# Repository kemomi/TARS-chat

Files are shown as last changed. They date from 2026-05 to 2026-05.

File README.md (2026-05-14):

# TARS-chat



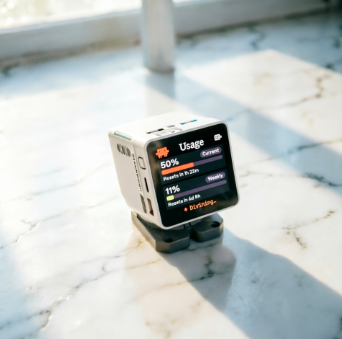
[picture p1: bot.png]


> 一款由 **Python** 驱动、嵌入 **树莓派 4B** 的超可爱迷你桌面机器人。
> 可显示表情、转动头部、对话交流,通过手机/浏览器远程控制。

[👉一起控制它👈](https://kemomi.github.io/TARS-chat/)

[日本語](./README_ja.md) | [English](./README_en.md) | [中文](./README_cn.md)

TARSchat

---

## ✨ 功能特性

- 😄 **丰富表情**: 中性 / 开心 / 难过 / 生气 / 惊讶 / 困倦,支持自定义 PNG 帧序列
- 🎮 **远程摇杆**: 网页拖动实时控制 Pan/Tilt 二自由度云台 (WebSocket 低延迟)
- 🗣️ **语音对话**: 内置 TTS (离线 pyttsx3 / 在线 edge-tts),可扩展 STT
- 🧠 **LLM 大脑**: 支持 OpenAI / Anthropic / 本地 Ollama,对话时自动联动表情与动作
- 🌐 **跨平台控制**: 任意浏览器/手机访问,无需安装 App
- 🔧 **模块化设计**: 舵机、显示、Web、语音、LLM 解耦,容易二次开发
- 📦 **一键部署**: `bash scripts/install.sh` 全自动安装

## 🗂 仓库结构

```
TARS-chat/
├── firmware/          # 树莓派固件 (Python)
│   ├── main.py        # 入口
│   ├── src/           # 核心模块
│   ├── config.yaml    # 配置文件
│   ├── assets/faces/  # 表情资源 (PNG 序列)
│   └── requirements.txt
├── web/               # Web 控制台 (HTML + Socket.IO)
├── schematics/        # 电路接线与原理图
├── stls/              # 3D 打印 STL 文件清单
├── case/              # 外壳设计源文件
├── scripts/           # 安装/测试脚本
├── systemd/           # 开机自启服务
└── docs/              # 文档、图片
```

## 🚀 快速开始

### 硬件准备
1. 看 [`硬件BOM + 接线表 + ASCII 接线图`](./schematics/BOM+接线表+ASCII接线图.md) 准备元件清单并完成接线
2. 看 [`结构件清单`](./stls/README.md) 打印 3D 结构件和所需的元器件 [`BOM清单`](./stls/BOM.md)
3. 装配机器人

### 烧录固件
```bash
git clone https://github.com/kemomi/TARS-chat.git
cd TARS-chat
pip install requirements.txt #安装依赖和环境
bash scripts/install.sh  #启动脚本
```

详细步骤见 [`固件烧录`](./firmware/固件安装文档.md)。

### 开始使用
```bash
sudo systemctl enable --now tars-chat
```
浏览器打开 `http://<树莓派IP>:8080` 即可看到控制台。

## 🛠 开发工作流

```bash
cd firmware
source venv/bin/activate
python ../scripts/test_servo.py   # 舵机自检
python main.py                    # 前台调试
```

修改 `../firmware/src/` 下任意文件后自启:
```bash
sudo systemctl restart tars-chat
```

## 📡 通信协议

| 类型 | 路径 | 说明 |
|---|---|---|
| HTTP POST | `/api/face` | `{expression:"happy"}` |
| HTTP POST | `/api/servo` | `{action:"set",pan:90,tilt:80}` 或 `nod`/`shake`/`center` |
| HTTP POST | `/api/speak` | `{text:"你好"}` |
| HTTP POST | `/api/chat` | `{text:"今天天气如何"}` — LLM 对话 |
| HTTP POST | `/api/chat/reset` | 清空对话历史 |
| HTTP GET  | `/api/status` | 查询当前状态 |
| WebSocket | `servo_stream` | 实时摇杆推流 (低延迟) |
| WebSocket | `dialogue_event`  | 多端对话同步 |

详细字段见 [`docs/API.md`](./docs/API.md)。LLM 接入见 [`docs/LLM.md`](./docs/LLM.md)。

## 🗺 路线图

见 [`ROADMAP`](./ROADMAP.md)。

## 🆙 Update docs

见[`更新文档`](./docs/更新文档.md)

## 🤝 贡献

欢迎提 Issue 与 PR!参与方式见 [`CONTRIBUTING`](./CONTRIBUTING.md)。

## 📄 许可证

[Apache 2.0](./LICENSE)

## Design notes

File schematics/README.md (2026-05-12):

# 硬件接线说明

## BOM (Bill of Materials)

| 序号 | 名称 | 数量 | 备注 |
|---|---|---|---|
| 1 | 树莓派 4B (2GB+)  | 1 | 主控,也可用 Pi Zero 2W |
| 2 | MicroSD 卡 32GB | 1 | Class 10 以上 |
| 3 | SG90 / MG90S 舵机 | 2 | Pan + Tilt 二自由度 |
| 4 | 3.5" HDMI / SPI 屏 | 1 | 320×240 或 480×320 |
| 5 | UBEC 5V 3A | 1 | 给舵机单独供电(关键!) |
| 6 | 18650 电池座 ×2 | 1 | 7.4V 输入 |
| 7 | 杜邦线若干 | - | 母对母 |
| 8 | M2/M3 螺丝包 | 1 | 与 STL 文件配套 |
| 9 | (可选) USB 麦克风  | 1 | 启用语音对话时需要 |
| 10 | (可选) 小喇叭 8Ω  | 1 | TTS 输出 |

> ⚠️ **关键提示**: 千万不要让舵机直接从树莓派 5V 引脚取电!舵机启动电流大,会导致树莓派复位。必须用独立 UBEC/降压模块。
关键避坑:舵机一定要走独立 UBEC 供电,千万别从树莓派 5V 引脚拉,会反复重启。 ASCII 接线图照着接就行

## GPIO 接线表

树莓派引脚使用 **BCM 编号**(`config.yaml` 中的 `pan_pin` 与 `tilt_pin` 也是 BCM)。

| 信号 | BCM | 物理引脚 | 接到 |
|---|-----|---|---|
| Pan 信号线 | 18  | 12 | 水平舵机橙色线 |
| Tilt 信号线| 13  | 33 | 俯仰舵机橙色线 |
| 公共 GND | - | 6 / 9 | UBEC GND + 舵机棕色线 |
| 5V (屏幕)  | - | 2 / 4 | HDMI 屏供电(若用 USB 供电就不接) |

**舵机供电独立走 UBEC**:
- UBEC 输入: 7.4V (电池) 或 12V 适配器
- UBEC 输出: 5V → 舵机红色线
- UBEC GND 必须与树莓派 GND **共地**

## 接线图(ASCII)

```
                 ┌──────────────────────┐
   电池 7.4V ───►│ UBEC 5V/3A           │──► 5V ───┬──► Pan 舵机 红
                 │                      │          └──► Tilt 舵机 红
                 │                      │──► GND ──┬──► Pan 舵机 棕
                 └──────────────────────┘          ├──► Tilt 舵机 棕
                                                   │
                       ┌─────────────────┐         │
   HDMI 屏 ◄───────────│ 树莓派 4B       │         │
                       │                 │         │
                       │   BCM 18 (Pin12)│──────────────► Pan 舵机 橙
                       │   BCM 13 (Pin33)│──────────────► Tilt 舵机 橙
                       │   GND (Pin 6)   │─────────┘
                       │                 │
                       │   USB ──────────│──► USB 麦克风 (可选)
                       │   3.5mm ────────│──► 小喇叭 (可选)
                       └─────────────────┘
```

## PCB(可选)

如果你想做转接板,本目录下应放置:
- `schematic.kicad_sch` — KiCad 原理图
- `pcb.kicad_pcb` — PCB 布线
- `gerber/` — 送厂打样用的 Gerber 文件

> 这些文件需要你用 KiCad 自行绘制,本仓库提供接线参考即可在面包板上跑通。

## 自检步骤

1. **不接舵机**先开机,确认树莓派、屏幕、网络正常
2. 连接舵机信号线,不接电源
3. 接通 UBEC,观察舵机是否轻微回中
4. 启动固件: `python main.py`
5. 浏览器打开 `http://<树莓派 IP>:8080` 测试摇杆

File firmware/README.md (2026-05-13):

# 固件安装指南

## 1. 系统要求

- 树莓派 4B / 3B+ / Zero 2W
- Raspberry Pi OS (Bookworm 或更新版本,64-bit 推荐)
- Python 3.9+

## 2. 一键安装

```bash
git clone https://github.com/kemomi/TARS-chat.git
cd TARS-chat
bash scripts/install.sh
```

`install.sh` 会自动完成:
- 安装 APT 依赖(pigpio、SDL2 等)
- 创建 Python 虚拟环境
- 安装 `requirements.txt`
- 启动 `pigpiod` 守护进程
- 注册 systemd 服务

## 3. 手动安装(如果自动脚本失败)

### 3.1 系统依赖

```bash
sudo apt update
sudo apt install -y python3-pip python3-venv python3-dev \
    pigpio python3-pigpio \
    libsdl2-dev libsdl2-image-dev libsdl2-ttf-dev \
    libportaudio2 \
    mpg123 espeak-ng
sudo systemctl enable --now pigpiod
```

### 3.2 Python 依赖

```bash
cd firmware
python3 -m venv venv
source venv/bin/activate
pip install --upgrade pip
pip install -r requirements.txt
```

### 3.3 运行(前台调试)

```bash
cd firmware
source venv/bin/activate
python main.py
```

此时浏览器访问 `http://<树莓派IP>:8080` 应该能看到控制台。

## 4. 开机自启 (systemd)

```bash
sudo cp systemd/tars-chat.service /etc/systemd/system/
sudo systemctl daemon-reload
sudo systemctl enable --now tars-chat
sudo systemctl status tars-chat   # 查看状态
```

查看日志:
```bash
journalctl -u tars-chat -f
# 或
tail -f /var/log/tars-chat.log
```

## 5. 配置说明

所有可调参数都在 `firmware/config.yaml`,常见修改:

| 项 | 说明 |
|---|---|
| `servo.pan_pin` | 如果接线换了 GPIO,改这里 |
| `servo.pan_range` | 缩小范围防止打到外壳 |
| `display.width/height` | 匹配你的屏幕分辨率 |
| `voice.enabled` | `true` 启用语音(需先装 pyttsx3 或 edge-tts) |
| `web.port` | 改 80 端口需要 `sudo` |

修改后重启服务:
```bash
sudo systemctl restart tars-chat
```

## 6. 常见问题

### Q1: 舵机疯狂抖动 / 不动?
- 检查是否启动 pigpiod: `sudo systemctl status pigpiod`
- 舵机必须有**独立 5V 供电**,不能从 Pi 引脚取电
- GND 必须共地

### Q2: `http://<IP>:8080` 打不开?
- 检查防火墙: `sudo ufw allow 8080`
- 确认服务运行: `sudo systemctl status tars-chat`
- 同一局域网内访问

### Q3: 表情不显示,只有占位文字?
- 检查 `firmware/assets/faces/` 下是否有 PNG 文件
- 资源规格见 [assets/faces/README.md](../assets/faces/README.md)

### Q4: 想脱离桌面环境跑(纯命令行启动)?
- 编辑 `src/face_display.py` 中的 `SDL_VIDEODRIVER`,改为 `"kmsdrm"`
- 或在 systemd 服务文件里加 `Environment=SDL_VIDEODRIVER=kmsdrm`

### Q5: 我用的不是树莓派,是 ESP32 / M5Stack?
- 本固件目前仅适配树莓派
- 如要移植到 MCU,需要重写舵机/显示驱动,但 Web 端协议(HTTP + Socket.IO)可以保留作为通信层

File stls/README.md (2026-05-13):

<!--
 * @Author: fbee3157 fbee3157@outlook.com
 * @Date: 2026-05-13 17:30:39
 * @LastEditors: fbee3157 fbee3157@outlook.com
 * @LastEditTime: 2026-05-13 17:31:47
 * @FilePath: \TARS-chat\stls\README.md
 * @Description: 这是默认设置,请设置`customMade`, 打开koroFileHeader查看配置 进行设置: https://github.com/OBKoro1/koro1FileHeader/wiki/%E9%85%8D%E7%BD%AE
-->
# 3D 打印件清单

本目录应包含以下 STL 文件(由你根据自己的尺寸建模或从社区下载)。下表为推荐结构,可作为建模依据。

## 文件清单

| 文件名 | 数量 | 推荐参数 | 说明 |
|---|---|---|---|
| `base.stl` | 1 | 0.2mm 层高 / 25% 填充 / 支撑 | 底座,容纳电池和电路板 |
| `body_front.stl` | 1 | 0.2mm / 20% / 无需支撑 | 机身前壳,挖屏幕窗口 |
| `body_back.stl` | 1 | 0.2mm / 20% / 无需支撑 | 机身后壳,留散热孔与接口 |
| `neck_tilt_arm.stl` | 1 | 0.16mm / 40% / 树状支撑 | 俯仰摆臂(连接 Tilt 舵机) |
| `neck_pan_base.stl` | 1 | 0.16mm / 40% | 水平转盘 |
| `servo_horn_adapter.stl`| 2 | 0.12mm / 80% | 舵机臂转接,匹配 SG90 出厂角  |
| `head_shell.stl` | 1 | 0.2mm / 15% | 头部外壳(屏幕载体) |
| `head_cover_top.stl` | 1 | 0.2mm / 15% | 顶盖 |
| `cable_clip.stl` | 2 | 0.2mm / 30% | 走线卡扣 |

## 推荐打印参数

- **材料**: PLA(室内桌面用足够;若放车里建议 PETG/ABS)
- **喷嘴**: 0.4mm
- **层高**: 外壳 0.2mm,关节 0.16mm
- **打印速度**: 50mm/s
- **温度**: 喷嘴 210°C / 热床 60°C(PLA)

## 螺丝清单(配套)

| 规格 | 数量 | 用途 |
|---|---|---|
| M2 × 6mm 自攻 | 8 | 舵机臂固定 |
| M3 × 8mm 自攻 | 12 | 机身合壳 |
| M3 × 16mm 内六角 | 4 | 底座承重 |

## 装配顺序

1. 打印全部 STL,用美工刀去除支撑毛刺
2. 把 Pan 舵机塞入 `neck_pan_base.stl` 槽位,用 M2 螺丝固定
3. `servo_horn_adapter.stl` 卡到 Pan 舵机臂上,再装到 `neck_tilt_arm.stl`
4. Tilt 舵机同理装入摆臂
5. 屏幕用双面胶或卡扣固定到 `head_shell.stl` 的窗口内
6. 树莓派、UBEC、电池座放入 `base.stl`,走线从顶部孔上来
7. 合壳前先通电测试一遍舵机方向,有问题就 `config.yaml` 里翻转角度范围

## 没有建模文件怎么办?

如果你还没有现成 STL,可以:
- **方案 A**: 用 Fusion 360 / OnShape 按上表自己建模(舵机槽尺寸 22.5×11.8×22.7mm)
- **方案 B**: 上 [Thingiverse](https://www.thingiverse.com/) / [Printables](https://www.printables.com/) 搜索 "Pan tilt camera mount SG90",选一套尺寸近的改一下
- **方案 C**: 直接买现成的舵机云台 + 亚克力外壳,跳过 3D 打印

> 建模完成后,把 STL 文件按上面的命名规则丢到本目录即可。

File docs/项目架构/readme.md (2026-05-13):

# TARS-chat 项目架构

## 一、目录结构

```
TARS-chat/
├── firmware/                      # 🎯 核心固件 (运行在树莓派)
│   ├── main.py                    # 启动入口,按序初始化各模块
│   ├── config.yaml                # 全局配置 (所有功能开关都在这)
│   ├── requirements.txt           # Python 依赖
│   ├── README.md                  # 固件安装指南
│   ├── assets/faces/              # 表情 PNG 帧序列
│   │   └── README.md
│   └── src/                       # 模块化代码
│       ├── __init__.py
│       ├── servo_controller.py    # 🦾 舵机控制 (Pan/Tilt 云台)
│       ├── face_display.py        # 😊 表情显示 (Pygame 渲染)
│       ├── voice_module.py        # 🗣️ TTS 语音播报
│       ├── camera_module.py       # 📷 摄像头采集
│       ├── face_tracker.py        # 👁️ 人脸检测 + 跟踪
│       ├── llm_provider.py        # 🧠 LLM 抽象层 (OpenAI/Anthropic/Ollama)
│       ├── dialogue.py            # 🎭 对话编排器 (整合 LLM/动作/语音/视觉)
│       └── web_server.py          # 🌐 Flask + Socket.IO 服务
│
├── web/                           # 🌐 Web 控制台 (前端)
│   └── web_control.html           # 单页应用 (表情/摇杆/对话/摄像头)
│
├── docs/                          # 📚 文档
│   ├── API.md                     # HTTP/WebSocket 接口
│   ├── LLM.md                     # 三种 LLM 后端接入指南
│   ├── CAMERA.md                  # 摄像头与视觉问答指南
│   └── ROADMAP.md                 # 版本规划
│
├── schematics/                    # ⚡ 电路设计
│   └── README.md                  # BOM + 接线表 + ASCII 接线图
│
├── stls/                          # 🖨️ 3D 打印件
│   └── README.md                  # 结构件清单 + 打印参数
│
├── case/                          # 📦 外壳源文件
│   └── README.md
│
├── scripts/                       # 🔧 工具脚本
│   ├── install.sh                 # 一键安装 (apt + pip + systemd)
│   └── test_servo.py              # 舵机自检
│
├── systemd/                       # 🚀 开机自启
│   └── tars-chat.service          # systemd unit
│
├── .github/workflows/
│   └── build.yml                  # CI: 语法检查 + 导入冒烟测试
│
├── README.md                      # 项目主页
├── CONTRIBUTING.md
├── LICENSE                        # Apache 2.0
└── .gitignore
```

## 二、分层架构

整个系统分四层,自顶向下:



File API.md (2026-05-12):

# API 参考

固件提供两套通信接口:**HTTP REST** 用于命令式控制,**WebSocket (Socket.IO)** 用于实时数据流。

Base URL: `http://<树莓派IP>:8080`

---

## HTTP REST API

### `GET /api/status`
查询当前所有状态。

**响应**
```json
{
  "ok": true,
  "servo": {"pan": 90, "tilt": 90, "backend": "pigpio"},
  "face": {
    "current": "neutral",
    "available": ["neutral", "happy", "sad", "angry", "surprised", "sleepy"]
  },
  "voice_enabled": false
}
```

### `POST /api/face`
切换表情。

**请求**
```json
{ "expression": "happy" }
```

**响应**
```json
{ "ok": true, "expression": "happy" }
```

### `POST /api/servo`
舵机控制。

**请求(set)**
```json
{ "action": "set", "pan": 120, "tilt": 80 }
```

**请求(其他动作)**
```json
{ "action": "center" }      // 回中
{ "action": "nod", "times": 2 }    // 点头
{ "action": "shake", "times": 3 }  // 摇头
```

**响应**
```json
{ "ok": true, "status": {"pan": 120, "tilt": 80, "backend": "pigpio"} }
```

### `POST /api/speak`
TTS 播报(需启用 voice)。

**请求**
```json
{ "text": "你好,我是 TARS。" }
```

### `POST /api/chat`
LLM 对话(需启用 llm,详见 [`LLM.md`](./LLM.md))。机器人会自动联动表情、动作和 TTS。

**请求**
```json
{ "text": "今天北京天气怎么样" }
```

**响应**
```json
{
  "ok": true,
  "response": {
    "say": "我没法查天气,你打开窗看看吧",
    "expression": "neutral",
    "motion": "shake"
  }
}
```

### `POST /api/chat/reset`
清空对话上下文,机器人会"忘记"之前的内容。
```json
{ "ok": true }
```

---

## WebSocket (Socket.IO)

### 客户端 → 服务端

#### `servo_stream`
摇杆实时推流,建议节流到 20~50ms 一次。

```js
socket.emit("servo_stream", { pan: 110, tilt: 95 });
```

### 服务端 → 客户端

#### `hello`
连接建立时推送。
```json
{ "msg": "TARS-chat ready" }
```

#### `face_changed`
任意端切换表情后广播,用于多端同步。
```json
{ "expression": "sad" }
```

#### `dialogue_event`
任意端发起 LLM 对话后广播。
```json
{
  "user": "你好",
  "response": {"say":"嗨!","expression":"happy","motion":"nod"}
}
```

---

## 第三方调用示例

### curl
```bash
curl -X POST http://192.168.1.10:8080/api/face \
     -H "Content-Type: application/json" \
     -d '{"expression":"happy"}'
```

### Python
```python
import requests
requests.post("http://192.168.1.10:8080/api/servo",
              json={"action": "set", "pan": 60, "tilt": 90})
```

### Home Assistant (REST command)
```yaml
rest_command:
  tars_happy:
    url: "http://192.168.1.10:8080/api/face"
    method: POST
    headers: { Content-Type: "application/json" }
    payload: '{"expression":"happy"}'
```

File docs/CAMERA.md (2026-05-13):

# 摄像头与人脸跟踪

TARS-chat 支持两类摄像头,自动探测:

| 摄像头 | 后端 | 备注 |
|---|---|---|
| Pi Camera v1/v2/v3, HQ Camera | picamera2 | 走 CSI 排线, 推荐 |
| USB UVC 摄像头 | opencv (V4L2) | 即插即用, 800 多万像素以下都行 |

---

## 1. 硬件准备

### CSI 摄像头(推荐)
- 树莓派 4B 有两个相机接口,接 CAM 那个
- 排线注意金属触点方向:Pi 侧朝 HDMI、摄像头侧朝镜头
- `raspi-config` → Interface Options → Camera 启用 (Bookworm 默认已启)

### USB 摄像头
- 直接插 USB,`ls /dev/video*` 看是否有 `/dev/video0`
- 多个摄像头时改 `config.yaml` 里 `device_index: 1` 之类

### 散热
人脸检测吃 CPU,Pi 4 全速跑约 50% 占用。如果没散热片建议加一个,不然降频之后会卡顿。

---

## 2. 安装依赖

### CSI 摄像头
```bash
sudo apt install -y python3-picamera2 python3-libcamera
```

### USB 摄像头
opencv 在树莓派上**强烈推荐 apt 装**,从 pip 装会编译几个小时:
```bash
sudo apt install -y python3-opencv libatlas-base-dev libjasper-dev
```

然后修改 `firmware/requirements.txt`,把 `opencv-python-headless` 那一行注释掉(避免 pip 重新装一遍冲突)。

测试摄像头能否被读到:
```bash
# CSI:
libcamera-hello -t 2000
# USB:
v4l2-ctl --list-devices
ffplay /dev/video0
```

---

## 3. 启用配置

`firmware/config.yaml`:

```yaml
camera:
  enabled: true            # ← 改这里
  width: 640
  height: 480
  fps: 15
  device_index: 0          # USB 用,CSI 摄像头忽略
  tracking:
    enabled: true          # 加载跟踪模块
    autostart: false       # true = 开机就跟踪 / false = Web 端手动开启
    pan_gain: 0.05         # 左右跟踪强度
    tilt_gain: 0.04        # 上下跟踪强度
    deadzone_pct: 0.08     # 中心 ±8% 不动 (防抖)
    lost_timeout: 1.5      # 失去目标 N 秒后回中
    detect_fps: 10         # 检测帧率
    min_face_size: 60      # 小于此像素的脸不识别
```

重启服务:
```bash
sudo systemctl restart tars-chat
```

---

## 4. 使用

启用后,Web 控制台会多出一个"视觉"卡片:

- **预览**:实时 MJPEG 推流,~15 FPS
- **绿色方框**:检测到人脸 + 跟踪开启
- **橙色方框**:检测到人脸,但跟踪未开
- **状态文字**:`SEARCHING` / `LOCKED` / `TRACKING`
- **人脸跟踪开关**:打开后舵机会自动跟着脸转
- **📷 拍照问**:拍一张照片连同问题一起发给 LLM (需要 vision 模型,如 gpt-4o)

---

## 5. 跟踪算法原理

```
摄像头帧 ──► Haar 级联检测 ──► 取最大人脸框 ──► 计算偏移
                                                  │
                                                  ▼
                          err_x = (face_cx - frame_cx) / (frame_cx)
                                                  │
                                       │err_x│ > deadzone?
                                              │ 否 ──► 不动
                                              │ 是
                                              ▼
                          pan_target = current_pan - err_x × gain × 90°
                                                  │
                                                  ▼
                                            servo.set_pan()
```

**为什么是 P-only 而不是 PID?** 摄像头检测有延迟(~70ms),又有积分项会震荡。比例控制 + 死区已经够稳。

**舵机转反了怎么办?** 把 `pan_gain` 或 `tilt_gain` 改成负数即可。

---

## 6. 视觉问答 (LLM with Vision)

`dialogue.py` 中的 `DialogueOrchestrator.chat()` 会自动检测以下关键词:
- 中文:`看到 / 看看 / 看一下 / 你看 / 前面 / 周围 / 环境 / 现在拍`
- 英文:`what do you see / look at / describe`

匹配时自动拍一张照片附加给 LLM。

**前提**: LLM Provider 需要支持视觉:
- ✅ OpenAI: `gpt-4o`, `gpt-4o-mini`, `gpt-4-vision-preview`
- ✅ Anthropic: `claude-haiku-4-5-20251001`, `claude-sonnet-4-6` (任意 Claude 3+ 都行)
- ❌ Ollama: 默认 `qwen2.5` 不支持,需换 `llava` / `qwen2-vl` 等多模态模型

示例对话:
```
你: "你前面有什么东西?"
TARS: "我看到一台笔记本电脑,屏幕上有一些代码,旁边有一杯咖啡。"  (顺便会点头)
```

---

## 7. 故障排查

### Q1: Web 端"视觉"卡片不显示
- 检查 `config.yaml` 中 `camera.enabled: true`
- 日志看是否报错: `journalctl -u tars-chat -n 50 | grep -i camera`

### Q2: 黑屏 / "无法打开摄像头"
- CSI: `libcamera-hello` 测一下,可能是排线松了
- USB: 检查 `/dev/video0` 是否存在;有时插着插着掉线,拔出来重插

### Q3: 人脸检测一闪一闪
- 光线太暗,Haar 算法在弱光下不稳定
- 把 `min_face_size` 调大到 80~100,过滤误检
- 增加 `min_neighbors` (在 face_tracker.py 里改)

### Q4: 舵机跟着人脸狂抖
- `pan_gain / tilt_gain` 太大,改小到 0.03 试试
- `deadzone_pct` 加大到 0.12
- 或者 `detect_fps` 降到 5(检测慢一点,反应不那么激进)

### Q5: 占 CPU 太高
- 降低 `camera.fps` 到 10
- 降低 `tracking.detect_fps` 到 5
- 降低 `camera.width/height` 到 320×240

### Q6: MJPEG 推流卡顿
- Pi 上同时跑 picamera2 + 推流会吃满网络,改用 320×240
- 或者只在需要看时才打开 Web 端 (推流是按需的)

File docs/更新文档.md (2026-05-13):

<!--
 * @Author: fbee3157 fbee3157@outlook.com
 * @Date: 2026-05-12 17:09:08
 * @LastEditors: fbee3157 fbee3157@outlook.com
 * @LastEditTime: 2026-05-13 14:55:13
 * @FilePath: \TARS-chat\docs\更新文档.md
 * @Description: 这是默认设置,请设置`customMade`, 打开koroFileHeader查看配置 进行设置: https://github.com/OBKoro1/koro1FileHeader/wiki/%E9%85%8D%E7%BD%AE
-->
# 部署流程

```bash
unzip TARS-chat.zip && cd TARS-chat
bash scripts/install.sh        # 一键装依赖 + systemd
python scripts/test_servo.py   # 先单独测舵机会不会动
sudo systemctl start tars-chat # 启动
# 浏览器打开 http://<树莓派IP>:8080
```
------------------------------------------------------------

V0.0.3-20260512

完成摄像头 + 人脸跟踪 + 视觉问答完成。
1. 摄像头双后端自动降级:picamera2(CSI) → opencv(USB) → mock。开发时没硬件也能跑,Web 控制台会显示一张"NO CAMERA"的占位图,所有 API 都不会崩。
2. 跟踪用 P-only 而不是 PID:摄像头检测有 70ms 左右延迟,积分项会让头部震荡。比例控制 + 中心 8% 死区,实测够稳。pan_gain / tilt_gain 是负的就反向跟踪——舵机装反时不用拆开,改 yaml 就行。

3. 视觉问答有两种触发方式:
隐式:dialogue 自动检测 "看到/前面/周围" 这类关键词,匹配就自动拍照附给 LLM
显式:Web 端"📷 拍照问"按钮、API 传 vision: true 强制走视觉

4. Anthropic 和 OpenAI 的 vision 消息格式不一样:

OpenAI 用 {type:"image_url", image_url:{url:"data:..."}},
Anthropic 用 {type:"image", source:{type:"base64",...}}。

在 BaseLLMProvider 里留了 _build_vision_message 钩子,Anthropic 子类重写就好。
5. MJPEG 推流帧上直接画检测框:在 Flask generator 里读 tracker.last_box 调 detector.draw() 叠加,前端只要  就能看到带框的实时画面,不用单独的画布 + WebSocket。
6. 截图用单独的内存 buffer:snapshot_base64() 编码质量 85,推流编码质量 70(省带宽)。给 LLM 的图要清楚一点,给浏览器看的图压一点没事。

几个使用注意
Pi 上一定 apt 装 OpenCV,别走 pip,后者要编译 4 小时还可能 OOM。
安装脚本已经处理了:venv --system-site-packages 让虚拟环境能用 apt 装的 cv2 和 picamera2
视觉问答必须用支持 vision 的模型:OpenAI 用 gpt-4o-mini,Anthropic 用任何 Claude 3+,Ollama 用 llava/qwen2-vl。普通文本模型收到图片会直接报错或忽略
跟踪反向了:看下舵机装的方向,把 pan_gain 或 tilt_gain 改成负数;不用改硬件

CPU 紧张:Pi 4 上同时跑 LLM 客户端 + 摄像头 + 表情显示,温度会上去。建议加散热片;或者把 detect_fps 降到 5,camera.fps 降到 10

下一个扩展是之前提过的还有两个:OpenSCAD 参数化外壳(把 STL 文件给你)和 STT 语音输入(让机器人能听见你说话,而不只是打字)。

V0.0.2-20260512

feat:更新几个设计决定:
1. 三种 Provider 用同一个抽象基类:OpenAIProvider、AnthropicProvider、OllamaProvider 都继承 BaseLLMProvider,只用实现 _chat() 一个方法。
换 Provider 只需要改 config.yaml 一行,不用动代码。
2. LLM 返回的是结构化指令,不是纯文本。LLM 输出 JSON {say, expression, motion},然后 DialogueOrchestrator 把三个字段分发给表情、舵机、TTS 三路并发执行——这样机器人会"一边点头一边说话",而不是"先说完再点头",体感差很多。
3. 容错降级:小模型(0.5B 这种)经常不遵守 JSON 格式,做了正则清洗 + JSON 解析失败时降级把整段当作 say,机器人虽然不动作但至少能说话,不会崩。
4. Anthropic API 的特殊处理:它的 system prompt 是单独字段,不在 messages 数组里,这个坑我已经在 AnthropicProvider._chat 里处理了。

几个使用建议:
最快上手:直接填 OpenAI key,5 分钟跑通。把 key 放环境变量别提交到 git
追求隐私:外接一台电脑跑 Ollama (OLLAMA_HOST=0.0.0.0:11434),让 Pi 通过局域网调用,比在 Pi 上本地跑流畅 10 倍
改性格:config.yaml 里改 system_prompt,记得保留 JSON 输出格式说明,否则编排器拿不到表情/动作字段
测试:不接舵机也能验证,mock 模式会把所有动作打日志

详细文档在 docs/LLM.md,三种后端的接入步骤、故障排查都在里面。
下一个准备做摄像头人脸跟踪还是再迭代 LLM(比如加流式输出/STT 让机器人能听)
Tars chatZIP ：
Download Llm providerPY Download DialoguePY DownloadConfigYAML DownloadWeb serverPY DownloadMainPY DownloadWeb controlCode · HTML Download LlmDocument · MD Download Download all

V0.0.1-20260512

1. 原 web_control.html 是纯前端模拟,按钮只会 alert() 提示。
add(fate)：新版本通过 Flask + Socket.IO 真正打通了浏览器 → 树莓派 → 舵机/屏幕/扬声器的链路,摇杆是通过 WebSocket 实时推流的(50ms 节流),延迟感觉跟玩游戏差不多。
2. 原 README "Rust + Python 驱动"
add(md)：新版本提供了完整 Python 固件,4 个核心模块解耦(舵机、表情、语音、Web),每个都可以单独测试。
3. 舵机后端三选一自动降级:优先 pigpio(硬件 PWM 抖动最小)→ 退到 RPi.GPIO(软件 PWM)→ 退到 Mock(在 Mac/Windows 上开发也能跑,只打日志不真的转)。这样即便没接树莓派也能调 Web 端。
4. 3D 打印:stls/README.md 推荐的 9 个结构件清单和打印参数,但仓库里没有实际的 .stl 文件——因为我没法在这里建模。
三个选项:
（1） 用 Fusion 360 / OnShape 按清单尺寸自己建(舵机槽 22.5×11.8×22.7mm 是 SG90 标准)
（2）上 Thingiverse 搜 "Pan tilt SG90 mount" 找现成的改一下
（3）直接买现成的舵机云台跳过 3D 打印这步

-------------------------------------------------------------------

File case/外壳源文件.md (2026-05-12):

# 外壳与组装

外壳的 STL 模型放在仓库 [stls/](../stls/) 目录,本目录用于放置:

- 外壳设计源文件 (`.f3d` / `.step` / `.scad`)
- 渲染效果图
- 装配视频/动图

## 整体尺寸参考

- 高度: ~180mm(含头部)
- 底座: 120 × 120mm
- 头部: 80 × 80 × 70mm

详细的打印参数与装配顺序见 [stls/README.md](../stls/README.md)。

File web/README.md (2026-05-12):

# 表情资源目录

将 PNG 序列帧放到对应子目录:

```
assets/faces/
├── neutral/      # 中性
│   ├── 0001.png
│   └── 0002.png  (可选,多帧自动循环作为眨眼)
├── happy/
├── sad/
├── angry/
├── surprised/
└── sleepy/
```

## 规格要求
- 分辨率: 与 `config.yaml` 中 `display.width × display.height` 一致(默认 320×240)
- 格式: PNG(支持透明背景)
- 文件名: 按 `0001.png`、`0002.png` 顺序命名,固件会自动按字典序循环
- 帧率: 固件默认按 10 FPS 播放

## 找不到资源会怎样?
固件会在屏幕上渲染占位文字(例如 `:: happy ::`),不会崩溃。

## 推荐做法
1. 用 Aseprite / Procreate / Photoshop 画 6 套像素风表情
2. 每套表情 2-4 帧形成"呼吸感"
3. 单帧也可,只是静态显示

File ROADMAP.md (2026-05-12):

# 路线图

## v0.1 (MVP) ✅
- [x] Pan/Tilt 舵机基础控制
- [x] 6 种表情显示
- [x] Web 控制台 (HTTP + WebSocket)
- [x] systemd 开机自启

## v0.2 ✅
- [x] LLM 集成:接入 OpenAI / Anthropic / 本地 Ollama
- [x] 对话联动:LLM 输出自动驱动表情 + 动作 + TTS
- [x] Web 端聊天界面 + 多端同步

## v0.3 (规划中)
- [ ] 摄像头模块:人脸跟踪、视觉问答 (LLM with vision)
- [ ] LLM 流式输出:边说边动,降低首字延迟
- [ ] 触摸交互:头顶触摸传感器(电容式)
- [ ] OTA 升级:Web 端一键更新固件
- [ ] STT:Whisper / Vosk 让机器人能听

## v1.0
- [ ] 完整的角色性格系统(JSON 配置)
- [ ] 第三方插件 API
- [ ] HomeAssistant / Matter 接入
- [ ] 移动 App (React Native)
- [ ] 多机器人组网(MQTT broker)
- [ ] M5Stack 版本固件分支

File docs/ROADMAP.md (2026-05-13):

# 路线图

## v0.1 (MVP) ✅
- [x] Pan/Tilt 舵机基础控制
- [x] 6 种表情显示
- [x] Web 控制台 (HTTP + WebSocket)
- [x] systemd 开机自启

## v0.2 ✅
- [x] LLM 集成:接入 OpenAI / Anthropic / 本地 Ollama
- [x] 对话联动:LLM 输出自动驱动表情 + 动作 + TTS
- [x] Web 端聊天界面 + 多端同步

## v0.3 ✅
- [x] 摄像头模块: picamera2 / opencv 双后端
- [x] 人脸跟踪: Haar 检测 + P 控制,自动跟脸转头
- [x] 视觉问答: LLM with vision,关键词触发自动拍照
- [x] MJPEG 推流到 Web 端

## v0.4 (规划中)
- [ ] LLM 流式输出:边说边动,降低首字延迟
- [ ] STT:Whisper / Vosk 让机器人能听
- [ ] 触摸交互:头顶触摸传感器(电容式)
- [ ] OTA 升级:Web 端一键更新固件
- [ ] OpenSCAD 参数化外壳

## v1.0
- [ ] 完整的角色性格系统(JSON 配置)
- [ ] 第三方插件 API
- [ ] HomeAssistant / Matter 接入
- [ ] 移动 App (React Native)
- [ ] 多机器人组网(MQTT broker)
- [ ] M5Stack 版本固件分支

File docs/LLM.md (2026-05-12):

# LLM 对话集成

TARS-chat 支持三种 LLM 后端,在 `firmware/config.yaml` 里改一行即可切换。

## 架构

```
用户输入 ──► /api/chat ──► DialogueOrchestrator
                                   │
                                   ├──► LLM Provider (OpenAI/Anthropic/Ollama)
                                   │         │
                                   │         ▼
                                   │    返回 JSON: {say, expression, motion}
                                   │
                                   ├──► FaceDisplay.show(expression)   # 表情切换
                                   ├──► ServoController.nod()/shake()  # 头部动作
                                   └──► VoiceModule.speak(say)         # TTS 播报
```

三路并发,用户感觉是"机器人一边点头一边说话"。

---

## 方案 A: OpenAI(最快上手)

### 1. 准备 API Key
- 注册 https://platform.openai.com,创建 API key
- 或用任何 OpenAI 兼容服务(DeepSeek、Moonshot、SiliconFlow 等)

### 2. 修改 `firmware/config.yaml`
```yaml
llm:
  enabled: true
  provider: "openai"
  api_key: "sk-xxxxxxxxxxxx"        # 或留空,从环境变量读
  model: "gpt-4o-mini"
  base_url: "https://api.openai.com/v1"
```

### 3. (推荐) 用环境变量保管 Key
不要把 key 提交到 git。改 systemd 服务:

```ini
# /etc/systemd/system/tars-chat.service
[Service]
Environment="OPENAI_API_KEY=sk-xxxxxxxxxxxx"
```

然后 `config.yaml` 里把 `api_key` 留空字符串即可。

### 4. 重启
```bash
sudo systemctl restart tars-chat
```

---

## 方案 B: Anthropic Claude

```yaml
llm:
  enabled: true
  provider: "anthropic"
  api_key: ""                                  # 留空读 ANTHROPIC_API_KEY
  model: "claude-haiku-4-5-20251001"           # 性价比之选;或 claude-sonnet-4-6
```

---

## 方案 C: Ollama 本地(无需联网)

### 1. 安装 Ollama

**在树莓派上跑(性能有限,适合 0.5B-3B 小模型)**:
```bash
curl -fsSL https://ollama.com/install.sh | sh
ollama pull qwen2.5:0.5b      # 0.5B 模型, Pi4 上勉强能用
# 或
ollama pull qwen2.5:3b        # 3B, 推荐 Pi5 或外置服务器
```

**外接电脑/服务器上跑(推荐)**:
让 Ollama 监听局域网:
```bash
# 编辑 /etc/systemd/system/ollama.service.d/override.conf
sudo systemctl edit ollama
```
添加:
```ini
[Service]
Environment="OLLAMA_HOST=0.0.0.0:11434"
```
然后:
```bash
sudo systemctl restart ollama
```

### 2. 配置 TARS-chat
```yaml
llm:
  enabled: true
  provider: "ollama"
  model: "qwen2.5:3b"
  base_url: "http://localhost:11434"           # 远程改成: http://192.168.x.x:11434
```

### 3. 推荐模型(中文)
| 模型 | 体积 | 适合设备 | 备注 |
|---|---|---|---|
| `qwen2.5:0.5b` | ~400MB | 树莓派 4B | 慢但能跑 |
| `qwen2.5:3b` | ~1.9GB | 树莓派 5 / Mac/PC  | 推荐起步 |
| `qwen2.5:7b` | ~4.4GB | 外置服务器 | 效果接近 GPT-3.5 |
| `llama3.2:3b` | ~2GB | Mac/PC | 英文为主 |

---

## 自定义性格(System Prompt)

在 `config.yaml` 的 `llm.system_prompt` 字段改:

```yaml
llm:
  system_prompt: |
    你是 TARS-chat,一只懒洋洋的猫型机器人。说话总带"喵"。
    回答时必须输出 JSON,不要任何代码块标记:
    {
      "say": "回答(简短,30字内)",
      "expression": "happy | sad | angry | surprised | sleepy | neutral",
      "motion": "nod | shake | center | none"
    }
```

**重点**: 一定要保留 JSON 输出格式说明,否则编排器无法解析。

---

## API 端点

### `POST /api/chat`
```json
// 请求
{ "text": "今天北京天气怎么样" }

// 响应
{
  "ok": true,
  "response": {
    "say": "我没法上网查天气哦,你可以打开窗看看~",
    "expression": "neutral",
    "motion": "shake"
  }
}
```

### `POST /api/chat/reset`
清空对话历史,机器人忘记之前聊过的内容。
```json
{}
```

---

## 故障排查

### Q1: Web 控制台一直显示"LLM 未启用"?
- 检查 `config.yaml` 中 `llm.enabled: true`
- 重启服务 `sudo systemctl restart tars-chat`
- 看日志 `journalctl -u tars-chat -n 50`

### Q2: 输入消息后一直显示"思考中..."不出来?
- OpenAI: 检查 key 是否有余额,网络是否能访问 api.openai.com
- Ollama: `curl http://localhost:11434/api/tags` 看模型是否加载
- 看后端日志看具体错误

### Q3: 机器人输出乱七八糟不是 JSON?
- 小模型(0.5B/1B)经常不遵守 JSON 输出格式
- 编排器有 fallback,会把整段当作 say,只是没有动作和表情
- 解决: 换大一点的模型,或在 prompt 里加更强约束

### Q4: 想让机器人主动开口(不等用户输入)?
- 在 `dialogue.py` 加个定时器,周期性调用 `dialogue.chat("说点什么")`
- 或加一个 "wakeword" 模块(需要 STT)

### Q5: 想流式输出(边说边动)?
- 当前是一句一句来的,LLM 全部生成完才执行动作
- 流式输出需要改 `LLMProvider._chat` 返回迭代器,然后 `DialogueOrchestrator` 做缓冲分句
- 这是下一步可以做的优化,先把基础链路跑通

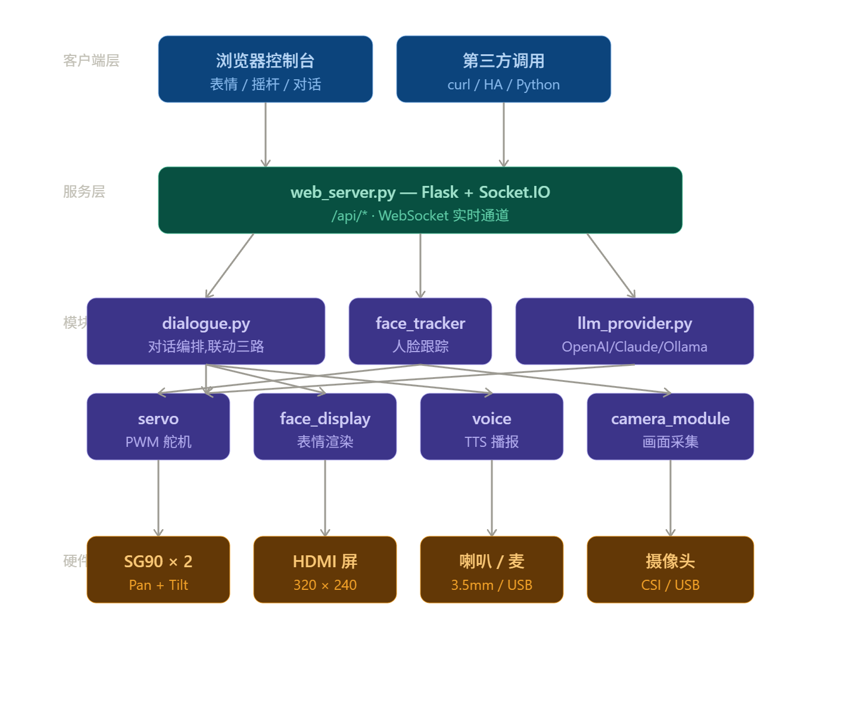
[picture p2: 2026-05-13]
docs/项目架构/image.png

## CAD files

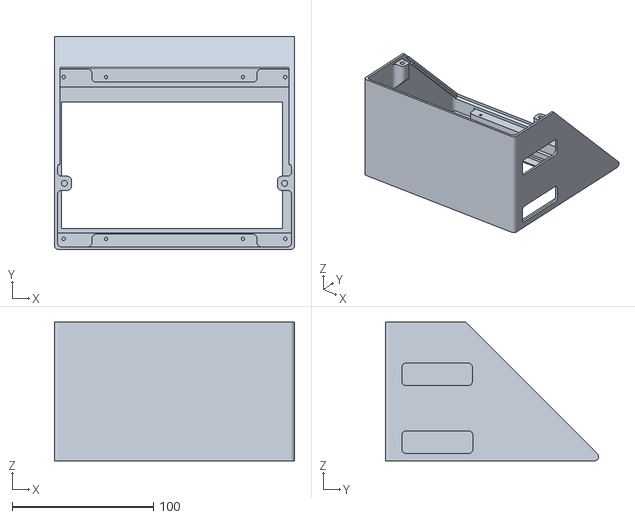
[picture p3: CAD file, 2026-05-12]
stls/3D打印结构件清单/Smart+display_stls/obj_1_Object_1.stl
169.9 x 151.1 x 98.3

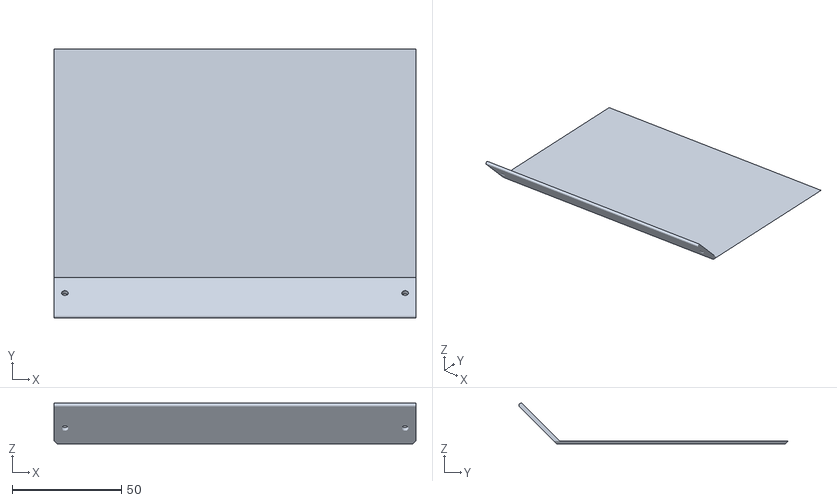
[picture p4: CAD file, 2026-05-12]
stls/3D打印结构件清单/Smart+display_stls/obj_4_Object_1.stl
165.9 x 123.5 x 18.7

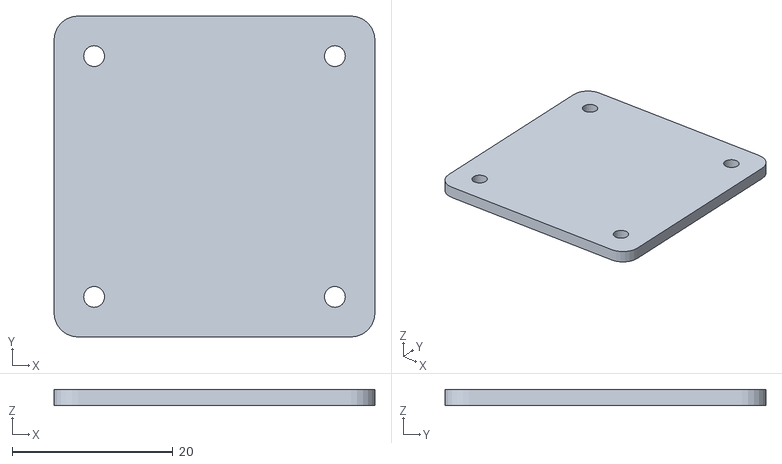
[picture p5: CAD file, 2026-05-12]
stls/3D打印结构件清单/Smart+display_stls/obj_3_Object_1.stl
40.0 x 40.0 x 2.00

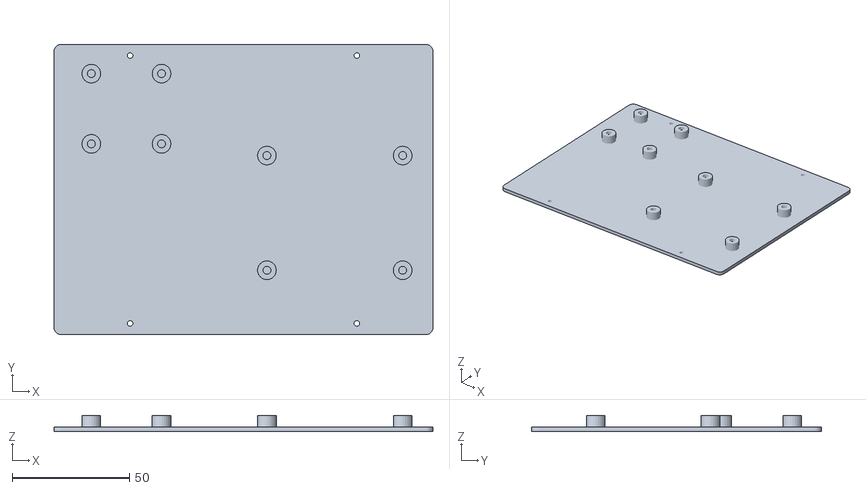
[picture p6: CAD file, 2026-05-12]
stls/3D打印结构件清单/Smart+display_stls/obj_2_Object_1.stl
161.9 x 124.0 x 7.00

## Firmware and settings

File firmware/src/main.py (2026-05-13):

#!/usr/bin/env python3
# -*- coding: utf-8 -*-
"""
TARS-chat 主程序入口
==================
启动顺序:
  1. 读取 config.yaml 配置
  2. 初始化舵机控制器 (Pan / Tilt)
  3. 初始化表情显示器 (HDMI / SPI LCD)
  4. 初始化语音模块 (可选)
  5. 初始化摄像头 + 人脸跟踪 (可选)
  6. 初始化 LLM 对话编排器 (可选, 含视觉问答)
  7. 启动 Web 服务 (Flask + Socket.IO)
"""
import logging
import signal
import sys
from pathlib import Path

import yaml

from src.servo_controller import ServoController
from src.face_display import FaceDisplay
from src.voice_module import VoiceModule
from src.llm_provider import create_provider
from src.dialogue import DialogueOrchestrator
from src.web_server import create_app, run_server

# ---------- 日志配置 ----------
logging.basicConfig(
    level=logging.INFO,
    format="%(asctime)s [%(levelname)s] %(name)s: %(message)s",
    handlers=[
        logging.StreamHandler(sys.stdout),
        logging.FileHandler("/var/log/tars-chat.log", mode="a", encoding="utf-8"),
    ],
)
logger = logging.getLogger("TARS-main")


def load_config(config_path: str = "config.yaml") -> dict:
    path = Path(__file__).parent / config_path
    if not path.exists():
        logger.error(f"配置文件不存在: {path}")
        sys.exit(1)
    with open(path, "r", encoding="utf-8") as f:
        cfg = yaml.safe_load(f)
    logger.info(f"配置加载完成: {path}")
    return cfg


def main():
    logger.info("=" * 50)
    logger.info("TARS-chat 启动中...")
    logger.info("=" * 50)

    cfg = load_config()

    # 1. 舵机
    servo = ServoController(
        pan_pin=cfg["servo"]["pan_pin"],
        tilt_pin=cfg["servo"]["tilt_pin"],
        pan_range=cfg["servo"]["pan_range"],
        tilt_range=cfg["servo"]["tilt_range"],
        freq=cfg["servo"].get("freq", 50),
    )
    servo.center()

    # 2. 表情
    face = FaceDisplay(
        width=cfg["display"]["width"],
        height=cfg["display"]["height"],
        fullscreen=cfg["display"].get("fullscreen", True),
        assets_dir=cfg["display"].get("assets_dir", "assets/faces"),
    )
    face.show("neutral")

    # 3. 语音(可选)
    voice = None
    if cfg.get("voice", {}).get("enabled", False):
        try:
            voice = VoiceModule(
                tts_engine=cfg["voice"].get("tts_engine", "pyttsx3"),
                lang=cfg["voice"].get("lang", "zh"),
            )
        except Exception as e:
            logger.warning(f"语音模块初始化失败,已禁用: {e}")

    # 4. 摄像头 + 人脸跟踪 (可选)
    camera = None
    tracker = None
    if cfg.get("camera", {}).get("enabled", False):
        try:
            from src.camera_module import CameraModule
            from src.face_tracker import FaceDetector, FaceTracker
            cam_cfg = cfg["camera"]
            camera = CameraModule(
                width=cam_cfg.get("width", 640),
                height=cam_cfg.get("height", 480),
                fps=cam_cfg.get("fps", 15),
                device_index=cam_cfg.get("device_index", 0),
            )
            camera.start()
            logger.info(f"摄像头启动: {camera.backend}")

            if cam_cfg.get("tracking", {}).get("enabled", True):
                tk_cfg = cam_cfg["tracking"]
                detector = FaceDetector(min_size=tk_cfg.get("min_face_size", 60))
                tracker = FaceTracker(
                    camera=camera, detector=detector, servo=servo,
                    pan_gain=tk_cfg.get("pan_gain", 0.05),
                    tilt_gain=tk_cfg.get("tilt_gain", 0.04),
                    deadzone_pct=tk_cfg.get("deadzone_pct", 0.08),
                    lost_timeout=tk_cfg.get("lost_timeout", 1.5),
                    detect_fps=tk_cfg.get("detect_fps", 10),
                )
                tracker.start()
                # 启动时是否自动开启跟踪
                if tk_cfg.get("autostart", False):
                    tracker.enable(True)
        except Exception as e:
            logger.warning(f"摄像头初始化失败: {e}")
            camera = None
            tracker = None

    # 5. LLM + 对话编排 (传入摄像头以支持视觉问答)
    llm = None
    try:
        llm = create_provider(cfg.get("llm", {}))
        if llm:
            logger.info(f"LLM 已启用: {type(llm).__name__}")
    except Exception as e:
        logger.warning(f"LLM 初始化失败: {e}")

    dialogue = DialogueOrchestrator(
        llm=llm, servo=servo, face=face, voice=voice, camera=camera,
    )

    # 6. 优雅退出
    def handle_exit(signum, frame):
        logger.info(f"收到信号 {signum},清理资源...")
        if tracker: tracker.cleanup()
        if camera:  camera.cleanup()
        servo.cleanup()
        face.cleanup()
        sys.exit(0)

    signal.signal(signal.SIGINT, handle_exit)
    signal.signal(signal.SIGTERM, handle_exit)

    # 7. Web 服务
    app, socketio = create_app(
        servo=servo, face=face, voice=voice,
        dialogue=dialogue, camera=camera, tracker=tracker,
        config=cfg,
    )
    run_server(
        app, socketio,
        host=cfg["web"]["host"],
        port=cfg["web"]["port"],
    )


if __name__ == "__main__":
    main()

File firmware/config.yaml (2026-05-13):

# =============================================================================
# TARS-chat 主配置文件
# =============================================================================

# ---------- 舵机 ----------
servo:
  pan_pin: 18          # BCM 编号, 水平转动
  tilt_pin: 13         # BCM 编号, 俯仰
  pan_range: [0, 180]  # 安全角度范围 (度)
  tilt_range: [30, 150]
  freq: 50             # PWM 频率 (Hz), 一般舵机为 50

# ---------- 显示 ----------
display:
  width: 320           # 表情屏分辨率
  height: 240
  fullscreen: true
  assets_dir: "assets/faces"

# ---------- 语音 ----------
voice:
  enabled: false       # 开启后需先安装依赖,见 README
  tts_engine: "pyttsx3"   # 可选: pyttsx3 (离线) | edge-tts (在线)
  lang: "zh"

# ---------- 摄像头 + 人脸跟踪 ----------
camera:
  enabled: false           # 改为 true 启用摄像头
  width: 640
  height: 480
  fps: 15
  device_index: 0          # USB 摄像头用 0/1/2..., CSI 摄像头忽略此项
  tracking:
    enabled: true          # 是否加载人脸跟踪模块
    autostart: false       # 启动时自动开始跟踪 (false: 在 Web 端手动开启)
    pan_gain: 0.05         # 左右跟踪增益,过大易抖
    tilt_gain: 0.04        # 上下跟踪增益
    deadzone_pct: 0.08     # 中心 ±8% 内不动
    lost_timeout: 1.5      # 失去目标多少秒后回中
    detect_fps: 10         # 检测帧率 (与 camera.fps 解耦, 节省 CPU)
    min_face_size: 60      # 最小人脸像素 (小于此值不检测)

# ---------- LLM 对话 ----------
llm:
  enabled: false          # 改为 true 启用对话功能
  provider: "ollama"      # ollama (本地) | openai | anthropic
  # ----- 通用 -----
  max_history: 10         # 保留最近 N 轮对话上下文
  system_prompt: |
    你是 TARS-chat,一个圆滚滚的桌面机器人。你的性格活泼、好奇、有点话痨。
    回答时必须严格输出 JSON,不要带任何代码块标记:
    {
      "say": "你要说的话(简短,30字以内,口语化)",
      "expression": "happy | sad | angry | surprised | sleepy | neutral",
      "motion": "nod | shake | center | none"
    }
    表情和动作要匹配语义,例如同意时点头(nod)、否定时摇头(shake)。

  # ----- Ollama 配置 (本地,推荐 Pi 上跑小模型,或外部服务器) -----
  model: "qwen2.5:3b"          # 树莓派上跑可换 "qwen2.5:0.5b"
  base_url: "http://localhost:11434"

  # ----- OpenAI 配置 (启用时取消下面注释并切换 provider) -----
  # provider: "openai"
  # api_key: ""             # 留空则读环境变量 OPENAI_API_KEY
  # model: "gpt-4o-mini"
  # base_url: "https://api.openai.com/v1"   # 兼容服务器在此改

  # ----- Anthropic 配置 -----
  # provider: "anthropic"
  # api_key: ""             # 留空则读环境变量 ANTHROPIC_API_KEY
  # model: "claude-haiku-4-5-20251001"


# ---------- Web ----------
web:
  host: "0.0.0.0"
  port: 8080

# ---------- 日志 ----------
log:
  level: "INFO"        # DEBUG / INFO / WARNING / ERROR

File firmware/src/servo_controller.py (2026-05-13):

# -*- coding: utf-8 -*-
"""
舵机控制模块 (Pan / Tilt 二自由度云台)
适配 SG90 / MG90S / MG996R 等 PWM 舵机
默认走 pigpio (硬件 PWM,抖动小),fallback 到 RPi.GPIO (软件 PWM)
"""
import logging
import time
import threading

logger = logging.getLogger("servo")

# ---------- 后端探测 ----------
try:
    import pigpio
    _BACKEND = "pigpio"
except ImportError:
    pigpio = None
    try:
        import RPi.GPIO as GPIO
        _BACKEND = "rpigpio"
    except ImportError:
        GPIO = None
        _BACKEND = "mock"
        logger.warning("未检测到 pigpio 或 RPi.GPIO,使用 Mock 后端(开发用)")


class ServoController:
    """
    PWM 舵机控制器
    angle 单位: 度 (0 ~ 180)
    """

    def __init__(self, pan_pin: int, tilt_pin: int,
                 pan_range=(0, 180), tilt_range=(30, 150), freq: int = 50):
        self.pan_pin = pan_pin
        self.tilt_pin = tilt_pin
        self.pan_range = pan_range
        self.tilt_range = tilt_range
        self.freq = freq
        self._lock = threading.Lock()
        self._pan_angle = 90
        self._tilt_angle = 90

        if _BACKEND == "pigpio":
            self.pi = pigpio.pi()
            if not self.pi.connected:
                raise RuntimeError("无法连接 pigpiod, 请执行: sudo systemctl start pigpiod")
            self.pi.set_mode(pan_pin, pigpio.OUTPUT)
            self.pi.set_mode(tilt_pin, pigpio.OUTPUT)
        elif _BACKEND == "rpigpio":
            GPIO.setmode(GPIO.BCM)
            GPIO.setup(pan_pin, GPIO.OUT)
            GPIO.setup(tilt_pin, GPIO.OUT)
            self._pan_pwm = GPIO.PWM(pan_pin, freq)
            self._tilt_pwm = GPIO.PWM(tilt_pin, freq)
            self._pan_pwm.start(0)
            self._tilt_pwm.start(0)
        logger.info(f"舵机初始化完成 (backend={_BACKEND}, pan={pan_pin}, tilt={tilt_pin})")

    # ---------- 角度 -> 脉宽 ----------
    @staticmethod
    def _angle_to_pulsewidth(angle: float) -> int:
        """0~180° -> 500~2500 us"""
        angle = max(0, min(180, angle))
        return int(500 + (angle / 180.0) * 2000)

    @staticmethod
    def _angle_to_duty(angle: float) -> float:
        """0~180° -> 2.5%~12.5% duty"""
        return 2.5 + (angle / 180.0) * 10.0

    # ---------- 底层写入 ----------
    def _write(self, pin: int, angle: float):
        if _BACKEND == "pigpio":
            self.pi.set_servo_pulsewidth(pin, self._angle_to_pulsewidth(angle))
        elif _BACKEND == "rpigpio":
            pwm = self._pan_pwm if pin == self.pan_pin else self._tilt_pwm
            pwm.ChangeDutyCycle(self._angle_to_duty(angle))
            time.sleep(0.02)
            pwm.ChangeDutyCycle(0)  # 防抖
        # mock 模式直接 pass

    # ---------- 公共 API ----------
    def set_pan(self, angle: float):
        angle = max(self.pan_range[0], min(self.pan_range[1], angle))
        with self._lock:
            self._pan_angle = angle
            self._write(self.pan_pin, angle)
        logger.debug(f"pan -> {angle}°")

    def set_tilt(self, angle: float):
        angle = max(self.tilt_range[0], min(self.tilt_range[1], angle))
        with self._lock:
            self._tilt_angle = angle
            self._write(self.tilt_pin, angle)
        logger.debug(f"tilt -> {angle}°")

    def set_both(self, pan: float, tilt: float):
        self.set_pan(pan)
        self.set_tilt(tilt)

    def smooth_to(self, pan: float, tilt: float, duration: float = 0.5, steps: int = 20):
        """平滑过渡,避免突然抽动"""
        p0, t0 = self._pan_angle, self._tilt_angle
        for i in range(1, steps + 1):
            ratio = i / steps
            self.set_pan(p0 + (pan - p0) * ratio)
            self.set_tilt(t0 + (tilt - t0) * ratio)
            time.sleep(duration / steps)

    def center(self):
        """回中"""
        self.smooth_to(90, 90, duration=0.4)

    def nod(self, times: int = 2):
        """点头动作"""
        for _ in range(times):
            self.smooth_to(self._pan_angle, 70, duration=0.2)
            self.smooth_to(self._pan_angle, 110, duration=0.2)
        self.smooth_to(self._pan_angle, 90, duration=0.2)

    def shake(self, times: int = 2):
        """摇头动作"""
        for _ in range(times):
            self.smooth_to(70, self._tilt_angle, duration=0.2)
            self.smooth_to(110, self._tilt_angle, duration=0.2)
        self.smooth_to(90, self._tilt_angle, duration=0.2)

    @property
    def status(self) -> dict:
        return {"pan": self._pan_angle, "tilt": self._tilt_angle, "backend": _BACKEND}

    def cleanup(self):
        try:
            if _BACKEND == "pigpio":
                self.pi.set_servo_pulsewidth(self.pan_pin, 0)
                self.pi.set_servo_pulsewidth(self.tilt_pin, 0)
                self.pi.stop()
            elif _BACKEND == "rpigpio":
                self._pan_pwm.stop()
                self._tilt_pwm.stop()
                GPIO.cleanup()
        except Exception as e:
            logger.error(f"清理舵机失败: {e}")

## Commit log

2026-05-12 Initial commit: Complete TARS-chat project
    [obj_1_Object_1.stl, obj_2_Object_1.stl, obj_3_Object_1.stl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]
2026-05-13 Upload project to GitHub main branch
    [obj_1_Object_1.stl, obj_2_Object_1.stl, obj_3_Object_1.stl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]
2026-05-13 Rename 结构件清单 + 打印参数.md to BOM.md
2026-05-14 更新 README.md
